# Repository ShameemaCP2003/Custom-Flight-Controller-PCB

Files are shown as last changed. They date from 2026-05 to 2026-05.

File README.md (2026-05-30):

# Custom Flight Controller PCB

Open-source STM32-based flight controller designed in KiCad for PX4 and ArduPilot-compatible UAV platforms.

---

## Overview

This project is a custom flight controller developed from scratch as a learning and engineering exercise in embedded hardware design, sensor integration, power management, and PCB development.

The design is inspired by modern flight controller architectures and incorporates a high-performance STM32 microcontroller, onboard inertial sensors, environmental sensing, multiple communication interfaces, and PWM outputs for UAV control applications.

---

## Features

- STM32F446RET6 ARM Cortex-M4 MCU
- ICM-42670-P 6-Axis IMU
- BMP390 Barometric Pressure Sensor
- USB Type-C Interface
- CAN Bus Support
- Multiple UART Interfaces
- Dual SPI Interfaces
- ADC Inputs
- GPIO Expansion
- 6 Servo/PWM Outputs
- SWD Programming Interface
- Onboard 3.3V Regulation
- Power Protection Circuitry

---

## Hardware Specifications

| Component | Part Number |
|---|---|
| MCU | STM32F446RET6 |
| IMU | ICM-42670-P |
| Barometer | BMP390 |
| Voltage Regulator | SPX3819 |
| Crystal | 3.2mm × 2.5mm |
| USB Interface | USB Type-C |

---

## Communication Interfaces

| Interface | Quantity |
|---|---|
| CAN Bus | 1 |
| UART | 3 |
| SPI | 2 |
| ADC | 2 |
| GPIO Input | 1 |
| GPIO Output | 2 |

---

## PWM Outputs

| Output |
|----------|
| Servo 1 |
| Servo 2 |
| Servo 3 |
| Servo 4 |
| Servo 5 |
| Servo 6 |

---

## PCB Statistics

| Parameter | Value |
|---|---|
| Layers | 2 |
| Nets | 79 |
| Pads | 291 |
| Vias | 297 |
| Unrouted Nets | 0 |
| ERC Status | Passed |
| DRC Status | Passed |

---

## Design Workflow

1. Requirements Definition
2. Component Selection
3. Schematic Design
4. ERC Validation
5. PCB Placement
6. PCB Routing
7. Ground Plane Implementation
8. DRC Verification
9. Prototype Preparation

---

## Current Status

- ✅ Schematic Complete
- ✅ PCB Layout Complete
- ✅ ERC Passed
- ✅ DRC Passed
- ⏳ Prototype Manufacturing Pending
- ⏳ Hardware Bring-Up Pending
- ⏳ PX4 Integration Pending

---

## Future Improvements

Planned future revisions include:

- Dual redundant IMU architecture
- SD card logging
- Additional CAN interfaces
- GPS connector
- Battery management system
- Power monitoring enhancements
- 4-layer PCB revision
- PX4 board support package
- ArduPilot board support package

---

## Repository Structure

hardware/
├── schematic/
└── pcb/

docs/
└── images/

firmware/

---

## Acknowledgements

This project was created as a learning and engineering exercise in custom flight controller design.

The development process was heavily influenced by the open-source embedded systems community, including the educational content and flight controller development resources shared by Timothy Kowalski.

## References

This project was developed with the help of open-source resources and educational content.

### Timothy Kowalski

Special thanks to Timothy Kowalski for sharing detailed flight controller development content and open-source hardware resources.

Reference Project:
- [Custom Flight Controller](https://github.com/HomeGliders/FCV2)

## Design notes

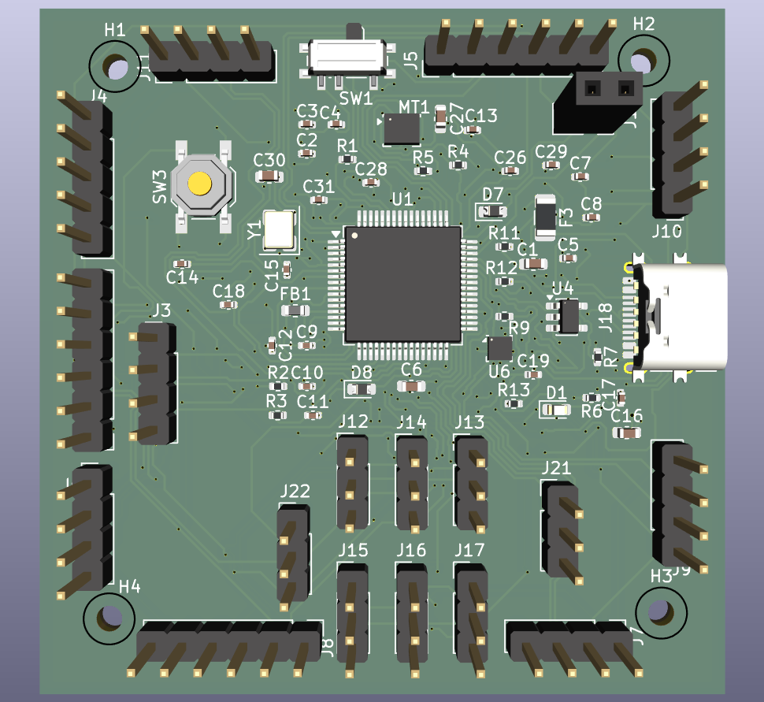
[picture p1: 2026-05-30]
hardware/docs/images/FC Front.png

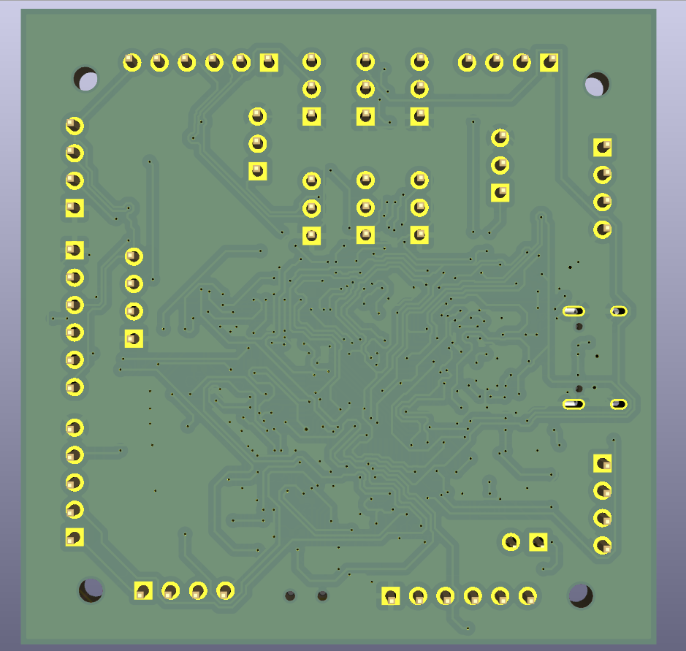
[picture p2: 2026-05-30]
hardware/docs/images/FC Back.png

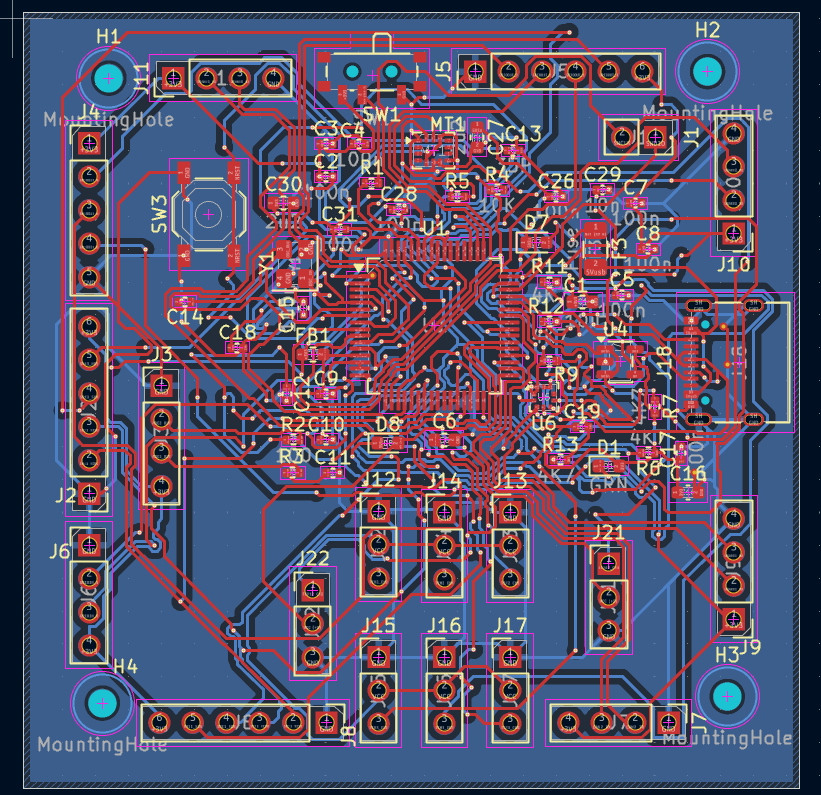
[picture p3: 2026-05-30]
hardware/docs/images/PCB Editor.png

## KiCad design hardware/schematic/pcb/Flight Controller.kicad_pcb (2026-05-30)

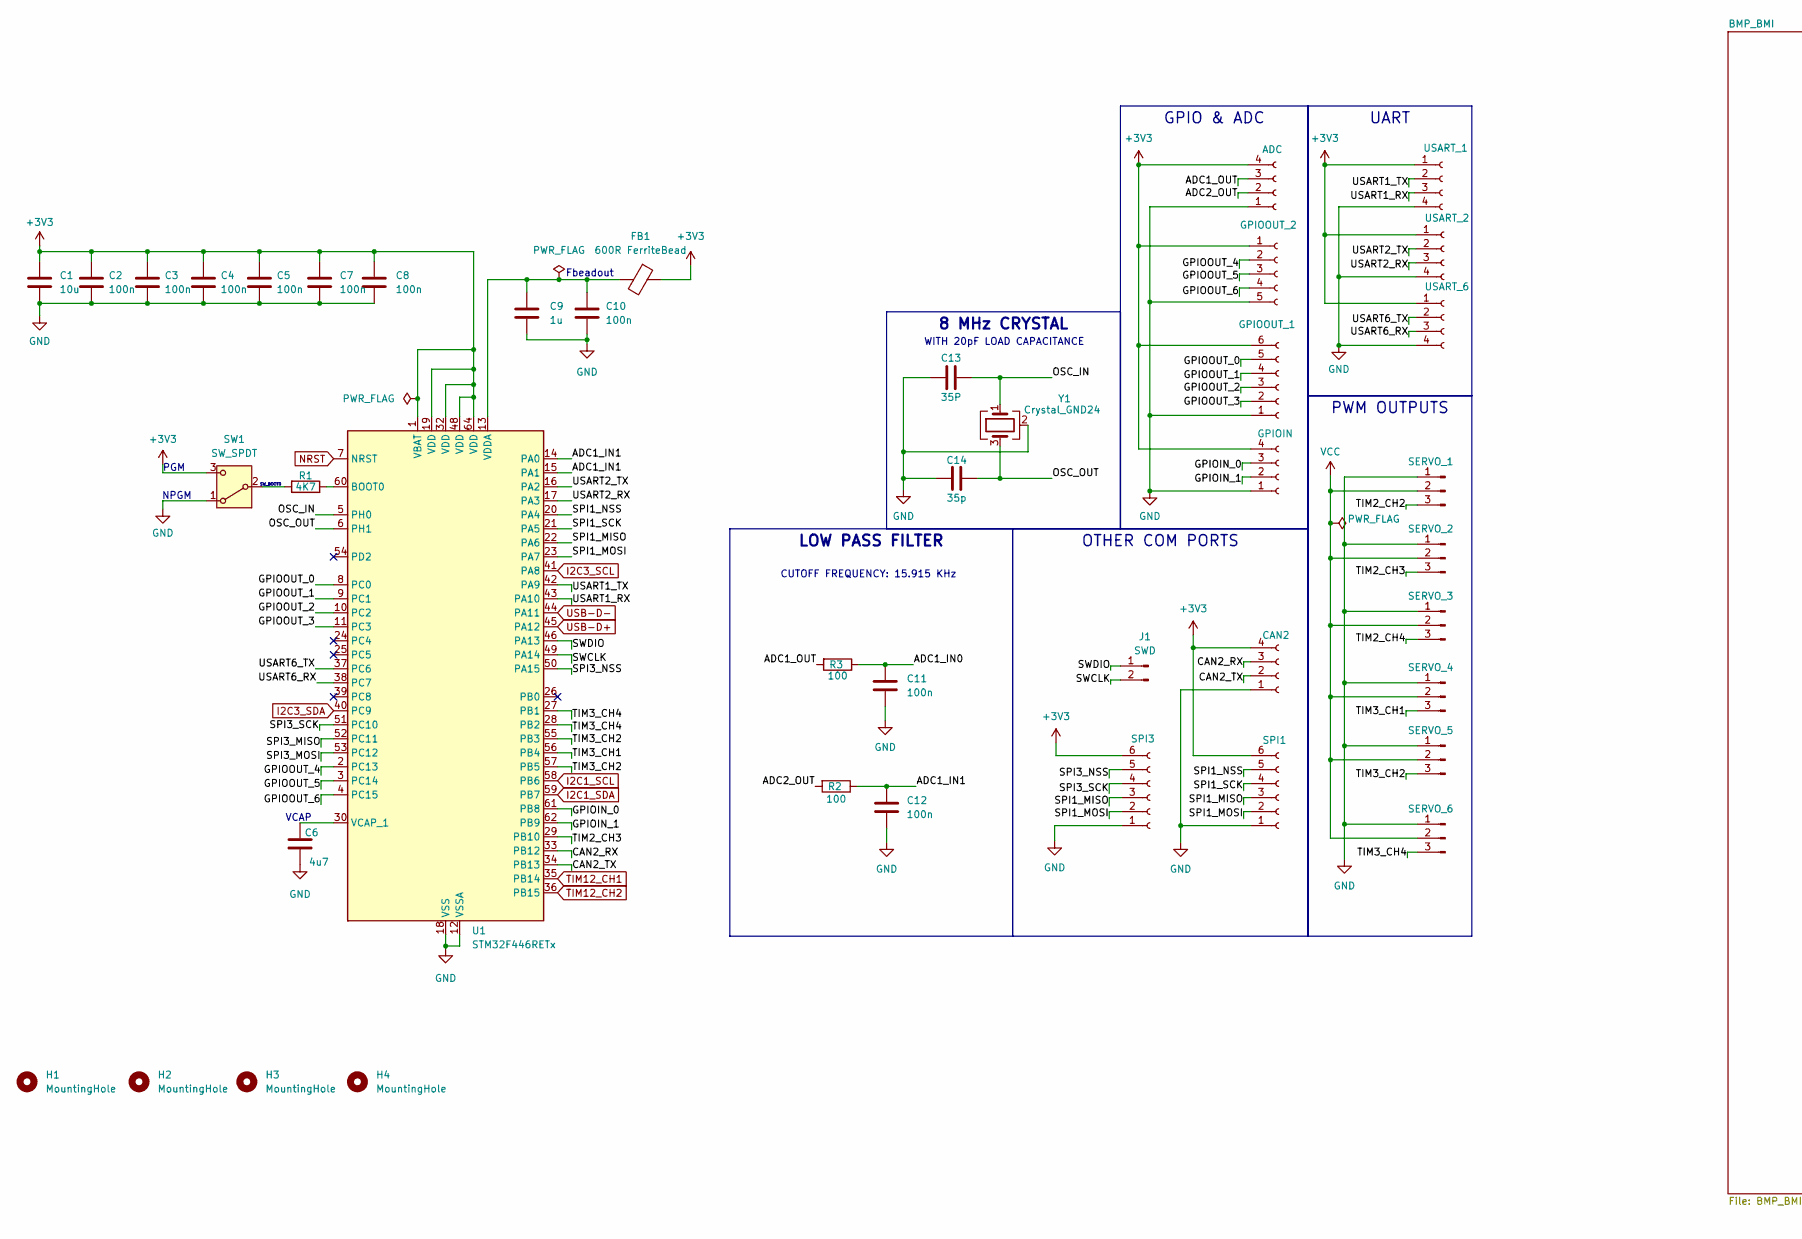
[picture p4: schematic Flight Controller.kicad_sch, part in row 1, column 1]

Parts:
C1: 10u; C_0603_1608Metric
C2, C3, C4, C5, C7, C8, C10, C11, C12: 100n; C_0402_1005Metric
C6: 4u7; C_0603_1608Metric
C9: 1u; C_0402_1005Metric
C13: 35P; C_0402_1005Metric
C14: 35p; C_0402_1005Metric
FB1: 600R FerriteBead; L_0603_1608Metric
H1, H2, H3, H4: MountingHole; MountingHole_2.2mm_M2
J1: SWD; PinSocket_1x02_P2.54mm_Vertical
J2: SPI3; PinHeader_1x06_P2.54mm_Vertical
J3: ADC; PinHeader_1x04_P2.54mm_Vertical
J4: GPIOOUT_2; PinHeader_1x05_P2.54mm_Vertical
J5: GPIOOUT_1; PinHeader_1x06_P2.54mm_Vertical
J6: GPIOIN; PinHeader_1x04_P2.54mm_Vertical
J7: CAN2; PinHeader_1x04_P2.54mm_Vertical
J8: SPI1; PinHeader_1x06_P2.54mm_Vertical
J9: USART_1; PinHeader_1x04_P2.54mm_Vertical
J10: USART_2; PinHeader_1x04_P2.54mm_Vertical
J11: USART_6; PinHeader_1x04_P2.54mm_Vertical
J12: SERVO_1; PinHeader_1x03_P2.54mm_Vertical
J13: SERVO_2; PinHeader_1x03_P2.54mm_Vertical
J14: SERVO_3; PinHeader_1x03_P2.54mm_Vertical
J15: SERVO_4; PinHeader_1x03_P2.54mm_Vertical
J16: SERVO_5; PinHeader_1x03_P2.54mm_Vertical
J17: SERVO_6; PinHeader_1x03_P2.54mm_Vertical
R1: 4K7; R_0402_1005Metric
R2, R3: 100; R_0402_1005Metric
SW1: SW_SPDT; SW_SPDT_PCM12
U1: STM32F446RETx; LQFP-64_10x10mm_P0.5mm
Y1: Crystal_GND24; Crystal_SMD_3225-4Pin_3.2x2.5mm

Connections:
+3V3: C1.1, C2.1, C3.1, C4.1, C5.1, C7.1, C8.1, FB1.1, J2.6, J3.4, J4.1, J5.6, J6.4, J7.4, J8.6, J9.1, J10.1, J11.1, SW1.3 (C), U1.1 (VBAT), U1.19 (VDD), U1.32 (VDD), U1.48 (VDD), U1.64 (VDD)
/ADC1_IN0: C11.1, R3.1
/ADC1_IN1: C12.1, R2.1, U1.14 (PA0), U1.15 (PA1)
/ADC1_OUT: J3.3, R3.2
/ADC2_OUT: J3.2, R2.2
/CAN2_RX: J7.3, U1.33 (PB12)
/CAN2_TX: J7.2, U1.34 (PB13)
/GPIOIN_0: J6.3, U1.61 (PB8)
/GPIOIN_1: J6.2, U1.62 (PB9)
/GPIOOUT_0: J5.5, U1.8 (PC0)
/GPIOOUT_1: J5.4, U1.9 (PC1)
/GPIOOUT_2: J5.3, U1.10 (PC2)
/GPIOOUT_3: J5.2, U1.11 (PC3)
/GPIOOUT_4: J4.2, U1.2 (PC13)
/GPIOOUT_5: J4.3, U1.3 (PC14)
/GPIOOUT_6: J4.4, U1.4 (PC15)
/OSC_IN: C13.1, U1.5 (PH0), Y1.1
/OSC_OUT: C14.1, U1.6 (PH1), Y1.3
/SPI1_MISO: J2.3, J8.3, U1.22 (PA6)
/SPI1_MOSI: J2.2, J8.2, U1.23 (PA7)
/SPI1_NSS: J8.5, U1.20 (PA4)
/SPI1_SCK: J8.4, U1.21 (PA5)
/SPI3_MISO: U1.52 (PC11)
/SPI3_MOSI: U1.53 (PC12)
/SPI3_NSS: J2.5, U1.50 (PA15)
/SPI3_SCK: J2.4, U1.51 (PC10)
/SWCLK: J1.2, U1.49 (PA14)
/SWDIO: J1.1, U1.46 (PA13)
/TIM2_CH2: J12.3
/TIM2_CH3: J13.3, U1.29 (PB10)
/TIM2_CH4: J14.3
/TIM3_CH1: J15.3, U1.56 (PB4)
/TIM3_CH2: J16.3, U1.55 (PB3), U1.57 (PB5)
/TIM3_CH4: J17.3, U1.27 (PB1), U1.28 (PB2)
/USART1_RX: J9.3, U1.43 (PA10)
/USART1_TX: J9.2, U1.42 (PA9)
/USART2_RX: J10.3, U1.17 (PA3)
/USART2_TX: J10.2, U1.16 (PA2)
/USART6_RX: J11.3, U1.38 (PC7)
/USART6_TX: J11.2, U1.37 (PC6)
GND: C1.2, C2.2, C3.2, C4.2, C5.2, C6.2, C7.2, C8.2, C9.2, C10.2, C11.2, C12.2, C13.2, C14.2, J2.1, J3.1, J4.5, J5.1, J6.1, J7.1, J8.1, J9.4, J10.4, J11.4, J12.1, J13.1, J14.1, J15.1, J16.1, J17.1, SW1.1 (A), U1.12 (VSSA), U1.18 (VSS), U1.31 (VSS), U1.47 (VSS), U1.63 (VSS), Y1.2 (G), Y1.4 (G); also elsewhere on the board
I2C1_SCL: U1.58 (PB6); also elsewhere on the board
I2C1_SDA: U1.59 (PB7); also elsewhere on the board
I2C3_SCL: U1.41 (PA8); also elsewhere on the board
I2C3_SDA: U1.40 (PC9); also elsewhere on the board
NRST: U1.7 (NRST); also elsewhere on the board
unnamed: R1.2, SW1.2 (B)
unnamed: R1.1, U1.60 (BOOT0)
unnamed: C6.1, U1.30 (VCAP_1)
unnamed: C9.1, C10.1, FB1.2, U1.13 (VDDA)
TIM12_CH1: U1.35 (PB14); also elsewhere on the board
TIM12_CH2: U1.36 (PB15); also elsewhere on the board
USB-D+: U1.45 (PA12); also elsewhere on the board
USB-D-: U1.44 (PA11); also elsewhere on the board
VCC: J12.2, J13.2, J14.2, J15.2, J16.2, J17.2

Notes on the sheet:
PGM
Fbeadout
CUTOFF FREQUENCY: 15.915 KHz
NPGM
WITH 20pF LOAD CAPACITANCE
VCAP
SW_BOOT0
GPIO & ADC
LOW PASS FILTER
OTHER COM PORTS
UART
8 MHz CRYSTAL
PWM OUTPUTS

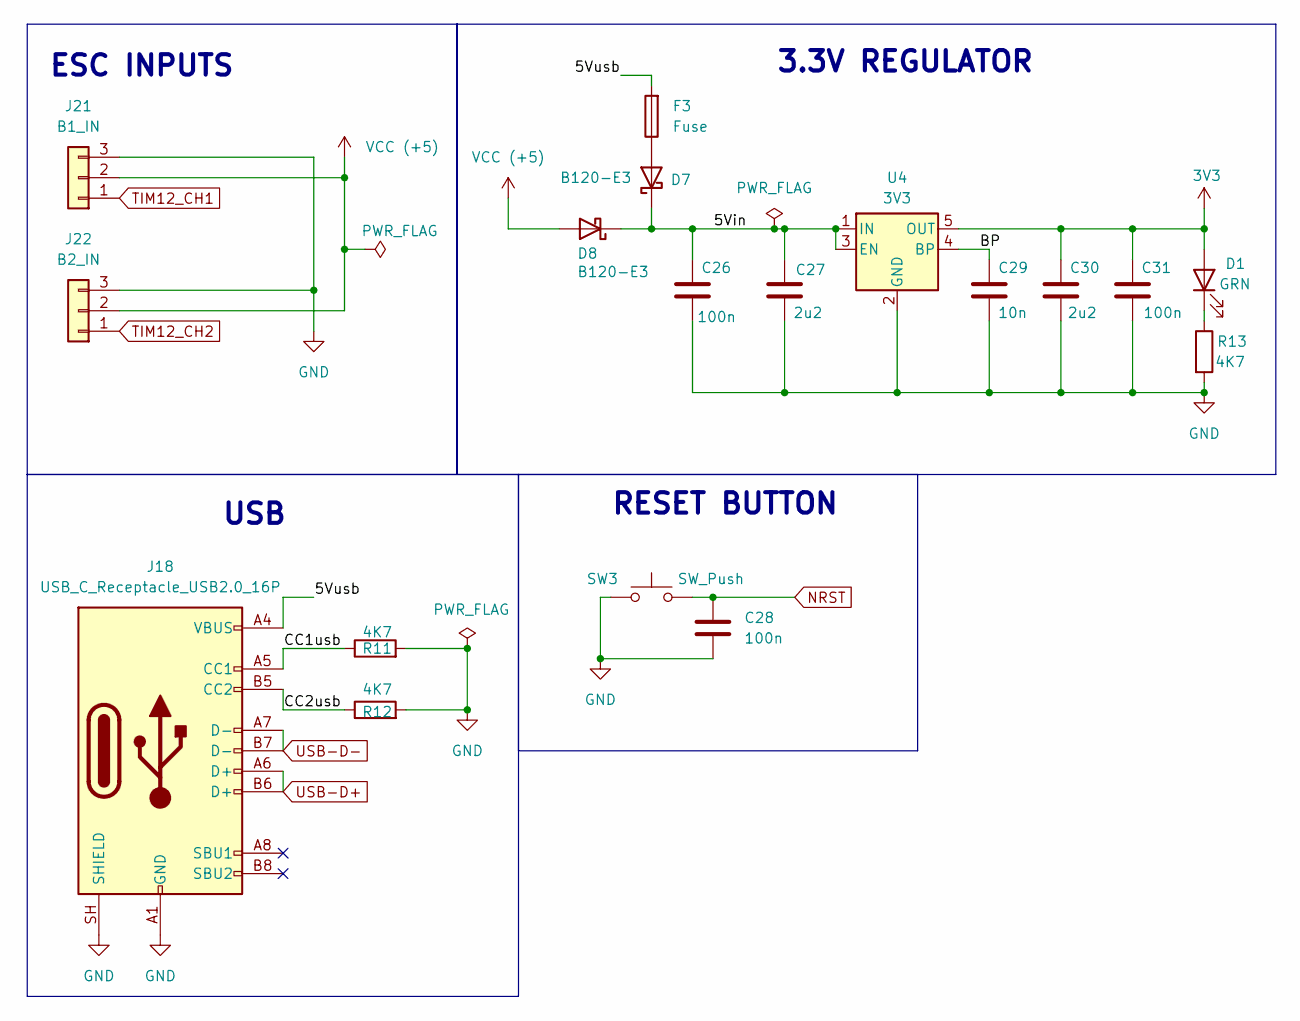
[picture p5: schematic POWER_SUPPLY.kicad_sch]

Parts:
C26, C28, C31: 100n; C_0402_1005Metric
C27, C30: 2u2; C_0603_1608Metric
C29: 10n; C_0402_1005Metric
D1: GRN; LED_0603_1608Metric
D7, D8: B120-E3; D_0603_1608Metric
F3: Fuse; Fuse_1206_3216Metric
J18: USB_C_Receptacle_USB2.0_16P; USB_C_Receptacle_XKB_U262-16XN-4BVC11
J21: B1_IN; PinHeader_1x03_P2.54mm_Vertical
J22: B2_IN; PinHeader_1x03_P2.54mm_Vertical
R11, R12, R13: 4K7; R_0402_1005Metric
SW3: SW_Push; SW_SPST_TL3342
U4: 3V3; SOT-23-5

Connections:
3V3: C30.1, C31.1, D1.2 (A), U4.5 (OUT); also elsewhere on the board
/POWER_SUPPLY/5Vin: C26.1, C27.1, D7.1 (K), D8.1 (K), U4.1 (IN), U4.3 (EN)
/POWER_SUPPLY/5Vusb: F3.2, J18.A4 (VBUS), J18.A9 (VBUS), J18.B4 (VBUS), J18.B9 (VBUS)
/POWER_SUPPLY/BP: C29.1, U4.4 (BP)
/POWER_SUPPLY/CC1usb: J18.A5 (CC1), R11.1
/POWER_SUPPLY/CC2usb: J18.B5 (CC2), R12.1
GND: C26.2, C27.2, C28.2, C29.2, C30.2, C31.2, J18.A1 (GND), J18.A12 (GND), J18.B1 (GND), J18.B12 (GND), J18.SH (SHIELD), J21.3, J22.3, R11.2, R12.2, R13.2, SW3.1, U4.2 (GND); also elsewhere on the board
NRST: C28.1, SW3.2; also elsewhere on the board
unnamed: D1.1 (K), R13.1
unnamed: D7.2 (A), F3.1
TIM12_CH1: J21.1; also elsewhere on the board
TIM12_CH2: J22.1; also elsewhere on the board
USB-D+: J18.A6 (D+), J18.B6 (D+); also elsewhere on the board
USB-D-: J18.A7 (D-), J18.B7 (D-); also elsewhere on the board
VCC (+5): D8.2 (A), J21.2, J22.2

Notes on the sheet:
RESET BUTTON
USB
ESC INPUTS
3.3V REGULATOR

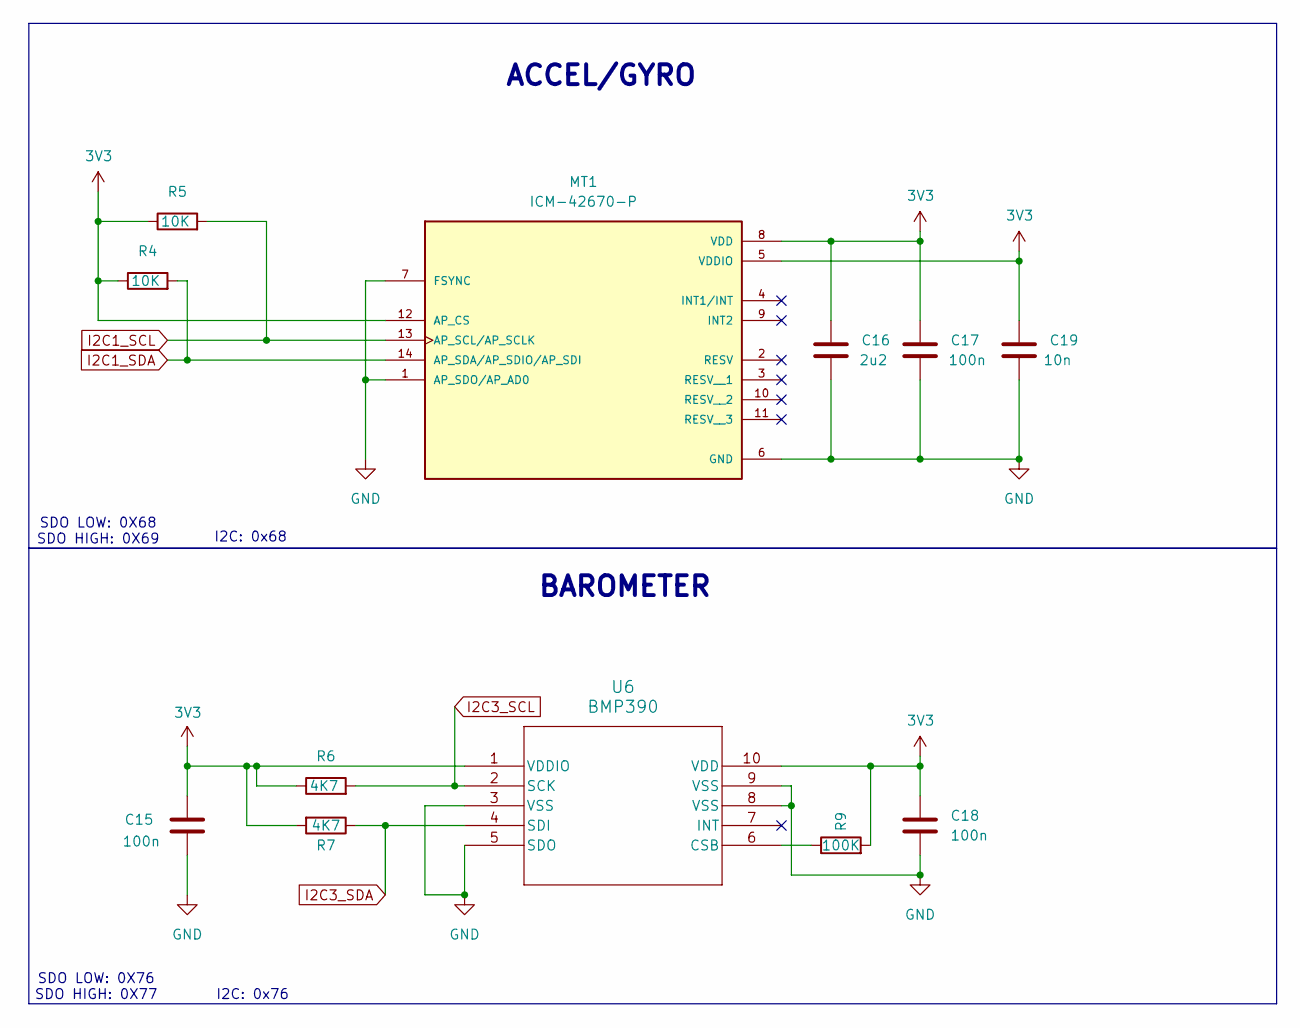
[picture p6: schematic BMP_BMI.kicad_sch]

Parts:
C15, C17, C18: 100n; C_0402_1005Metric
C16: 2u2; C_0603_1608Metric
C19: 10n; C_0402_1005Metric
MT1: ICM-42670-P; LGA-14_3x2.5mm_P0.5mm_LayoutBorder3x4y; PARTREV 1.1
R4, R5: 10K; R_0402_1005Metric
R6, R7: 4K7; R_0402_1005Metric
R9: 100K; R_0402_1005Metric
U6: BMP390; ST_HLGA-10_2x2mm_P0.5mm_LayoutBorder3x2y

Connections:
3V3: C15.1, C16.1, C17.1, C18.1, C19.1, MT1.5 (VDDIO), MT1.8 (VDD), MT1.12 (AP_CS), R4.1, R5.1, R6.1, R7.2, R9.2, U6.1 (VDDIO), U6.10 (VDD); also elsewhere on the board
GND: C15.2, C16.2, C17.2, C18.2, C19.2, MT1.1 (AP_SDO/AP_AD0), MT1.6 (GND), MT1.7 (FSYNC), U6.3 (VSS), U6.5 (SDO), U6.8 (VSS), U6.9 (VSS); also elsewhere on the board
I2C1_SCL: MT1.13 (AP_SCL/AP_SCLK), R5.2; also elsewhere on the board
I2C1_SDA: MT1.14 (AP_SDA/AP_SDIO/AP_SDI), R4.2; also elsewhere on the board
I2C3_SCL: R6.2, U6.2 (SCK); also elsewhere on the board
I2C3_SDA: R7.1, U6.4 (SDI); also elsewhere on the board
unnamed: R9.1, U6.6 (CSB)

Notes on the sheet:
SDO LOW: 0X76 SDO HIGH: 0X77
ACCEL/GYRO
I2C: 0x68
I2C: 0x76
SDO LOW: 0X68 SDO HIGH: 0X69
BAROMETER

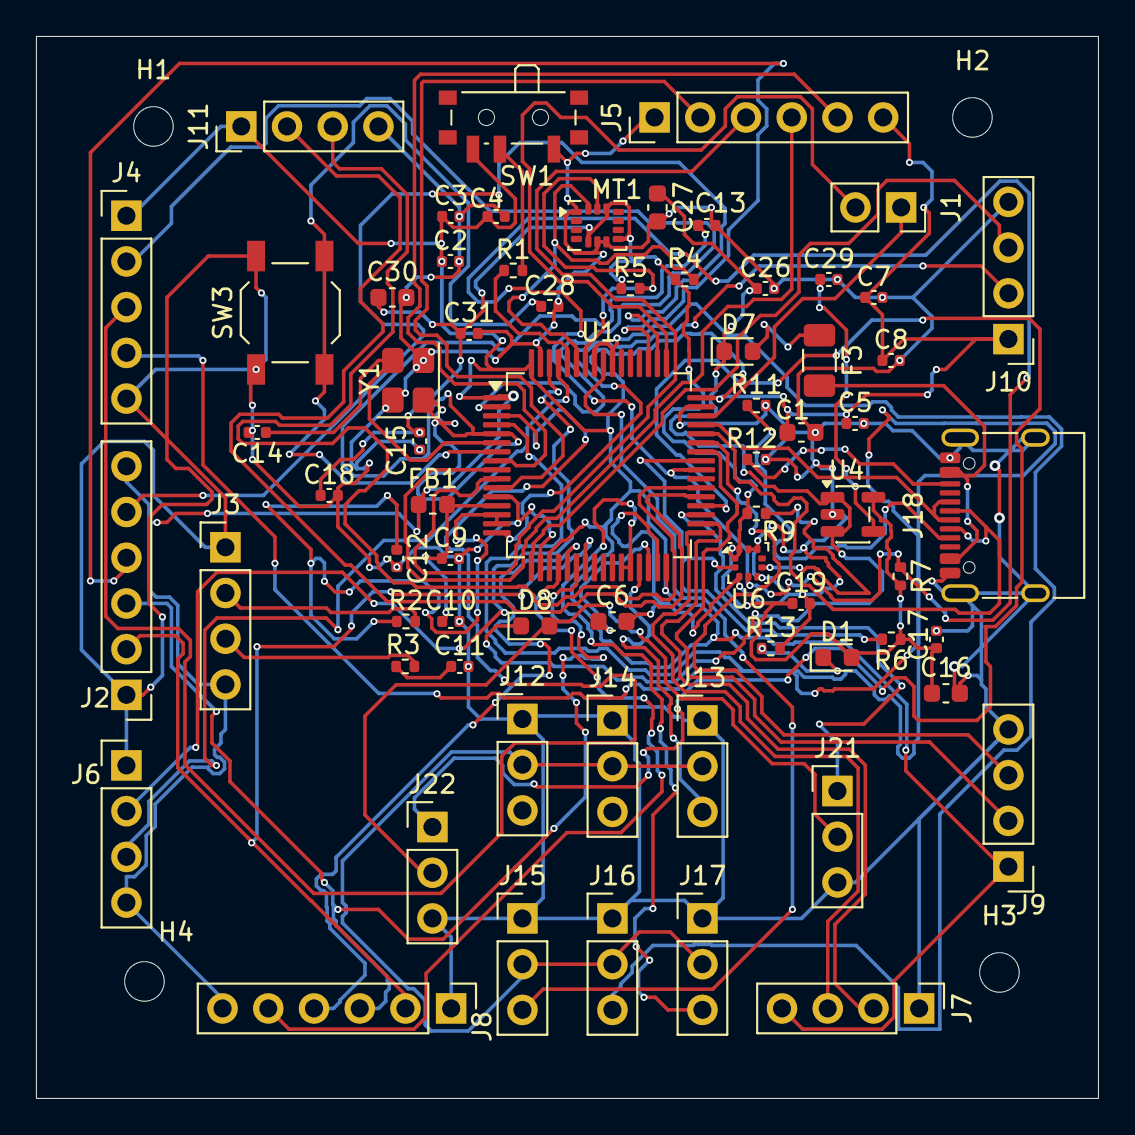
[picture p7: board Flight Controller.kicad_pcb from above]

Board: 2 copper layers, 59.0 x 59.0 mm, 72 parts (0 on the bottom side), 61 nets.
